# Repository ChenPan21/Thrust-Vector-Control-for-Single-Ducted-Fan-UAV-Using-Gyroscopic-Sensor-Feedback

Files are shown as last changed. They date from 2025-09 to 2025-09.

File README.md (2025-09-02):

<p align="right">
  <a href="README-en.md">English</a> | <a href="README.md">中文</a>
</p>

# 单函道风扇无人机的推力矢量控制(TVC)

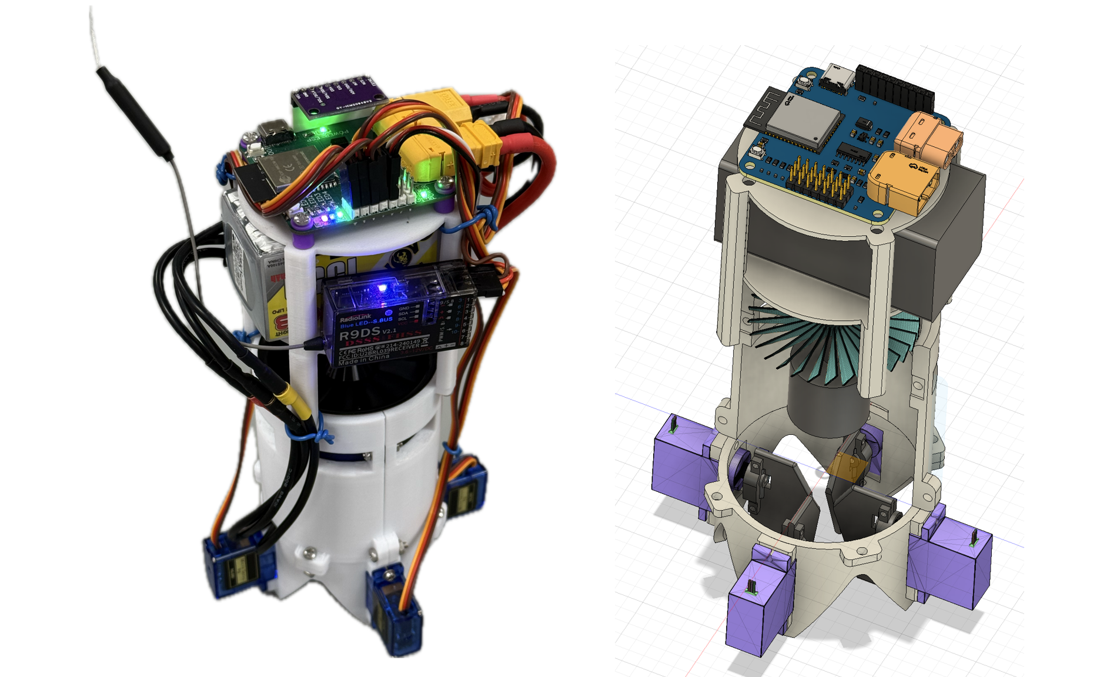
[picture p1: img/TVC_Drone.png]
项目成品图


这是一个关于使用陀螺仪传感器反馈，为单函道风扇无人机（UAV）实现推力矢量控制（Thrust Vector Control, TVC）的项目。

---

## 🚀 项目简介

### 什么是推力矢量控制 (TVC)？

让我们先来玩一个小游戏，想象一下，你想要用手掌托住一瓶倒立的矿泉水，并让它保持垂直不倒。

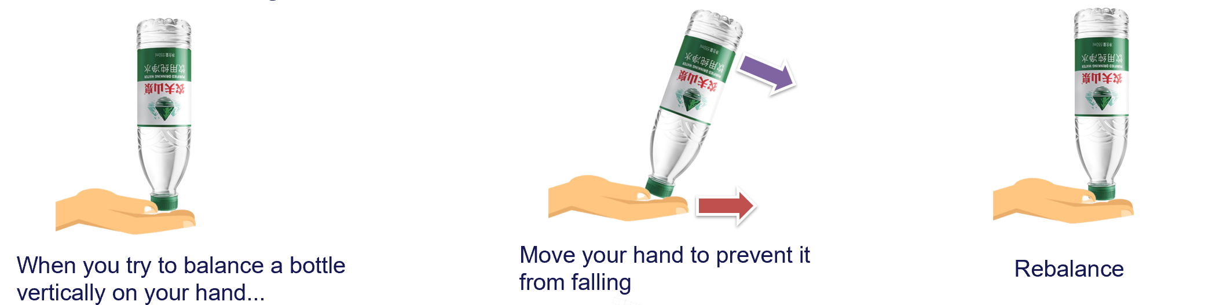
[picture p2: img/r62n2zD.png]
倒立水瓶
 
当水瓶开始向左倾斜时，你的手会下意识地向左移动，产生一个反作用力，将水瓶推回中心。当它向右倾斜时，你的手又会向右移动来纠正它，从而实现平衡。
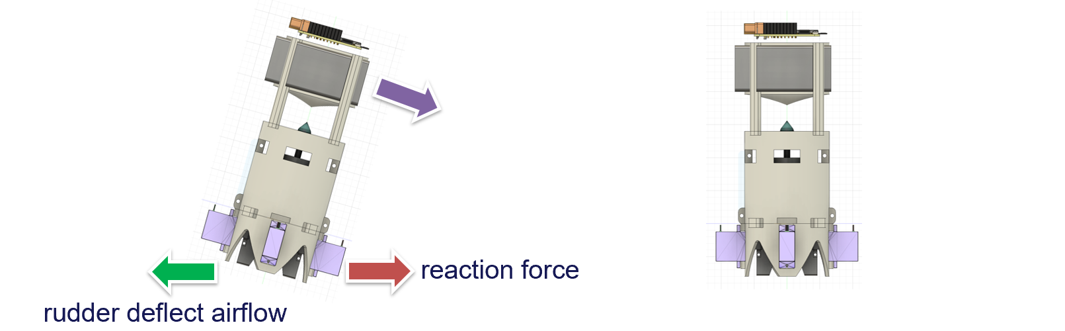
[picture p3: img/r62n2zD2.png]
本项目TVC 原理

本项目无人机的**推力矢量控制**原理与此非常相似。它底部的四个舵面就像你的手，机身就像那瓶水。当无人机的陀螺仪传感器（相当于咱们的眼睛和平衡感）检测到机身发生倾斜时，控制器会立刻命令相应的舵面偏转，改变高速气流的方向。这样，气流就会产生一个反作用力，将机身“推”回平衡状态。

通过对这个反作用力进行精准、快速的控制，无人机就能在没有多个螺旋桨的情况下，实现悬停、滚转、俯仰和偏航等全姿态的稳定飞行。

### 项目意义

与依赖电机转速差进行姿态控制的传统多旋翼无人机相比，单函道风扇 TVC 无人机具有以下显著优势：

* **增强的机动性:** 通过舵面偏转产生额外的控制力矩，显著增强了悬停和低速飞行时的姿态调整能力。
* **解耦控制:** 避免了传统多旋翼“倾斜机身以实现偏航”的耦合问题，可以实现更精准的平移和转向操控。
* **更高的安全性与效率:** 函道设计包裹了高速旋转的桨叶，提升了安全性，同时优化了气动效率。
* **结构简化:** 仅需1个函道风扇+4个舵机即可实现全姿态控制，大幅简化了机械结构和电子驱动部分，减轻了重量和体积。

---

### 项目难点

* **高频姿态解算与实时闭环控制**
* **TVC控制抵消单发动机的自旋扭矩**
* **推力矢量舵机控制与气动响应非线性**
* **硬件轻量化设计 | 高低功率电源隔离 | FreeRTOS 多任务并行**

---

## 🛠️ 硬件设计

硬件系统是实现稳定飞行的基础。本项目经历了从分布式模块到高度集成化设计的多次迭代，最终实现了结构紧凑、高可靠性的硬件平台。

### 1. 机械结构

机械结构经过了三个主要版本的迭代，全部采用 PLA 材料进行 3D 打印，兼顾了轻量化与结构刚性。

* **V1: 初版验证**
    <br>
    <p align="center">
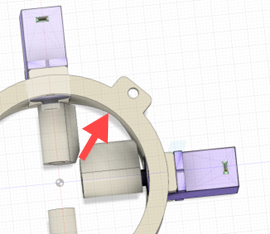
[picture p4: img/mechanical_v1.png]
第一版设计
      
    </p>
    
    * 采用分体式结构，主要用于验证各部件的装配尺寸和干涉问题。
    * **问题:** 封闭的底部结构阻挡了对角线方向的气流，导致矢量控制失效。

* **V2: 气流优化与双电池方案**

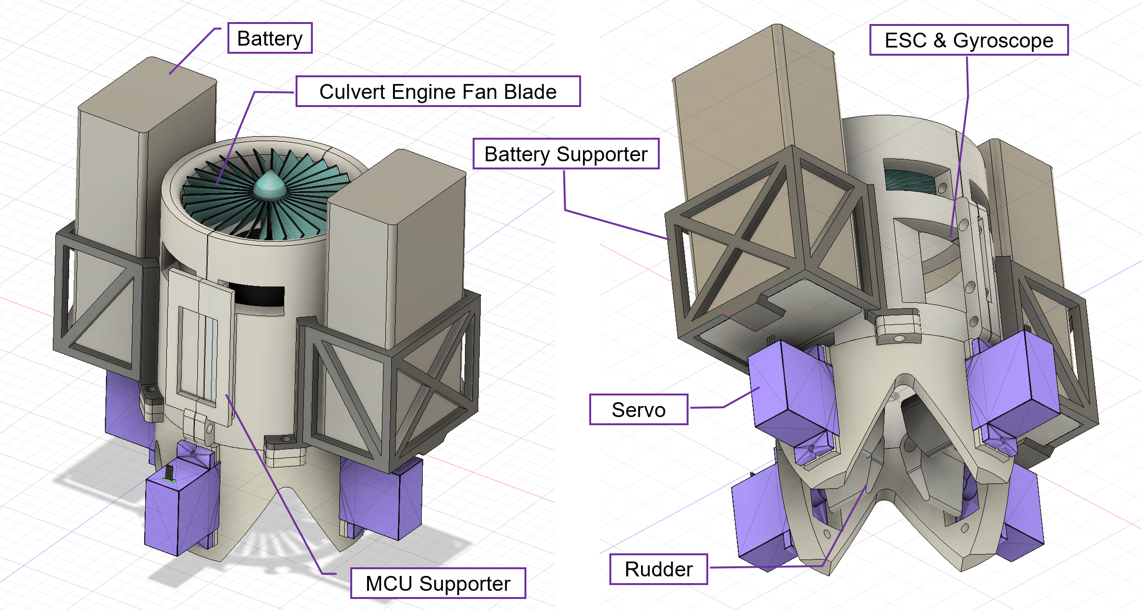
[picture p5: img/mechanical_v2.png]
第二版结构图
  

    * 底部对角区域进行大面积开孔，解决了气流遮挡问题，并增大了舵机行程。
    * 采用双电池对称布局以平衡重心，并设计了电调散热通道。
    * **问题:** 双电池方案导致总重量过大，接近推力极限，续航能力差。

* **V3: 最终版 - 垂直堆叠集成化设计**

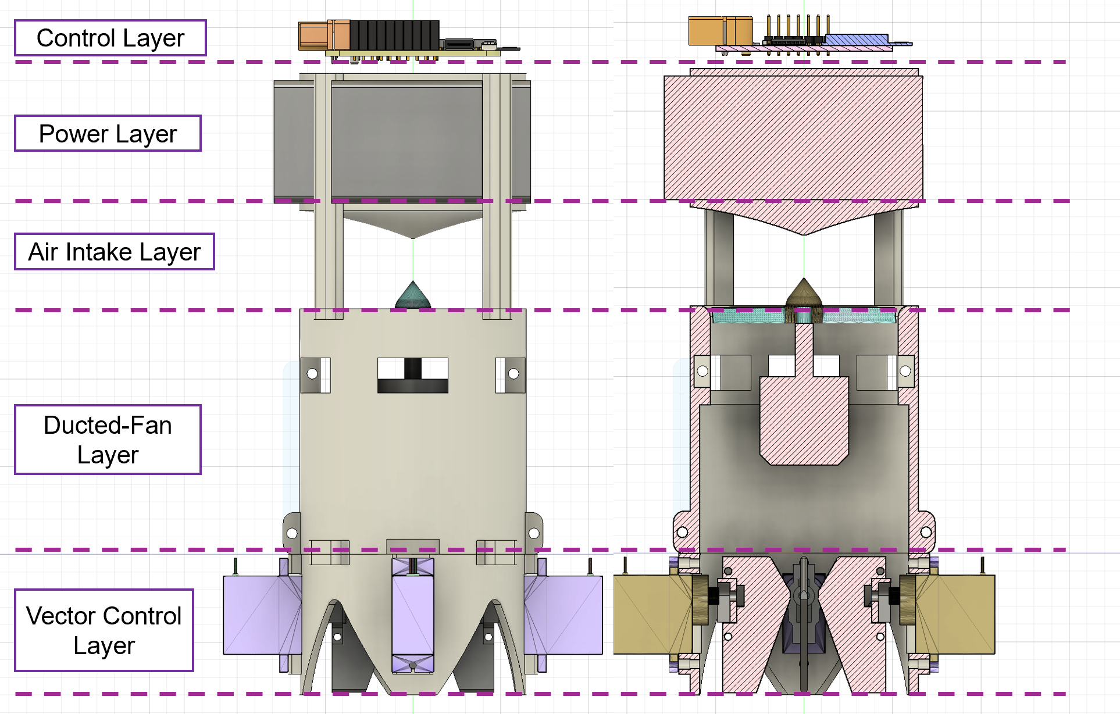
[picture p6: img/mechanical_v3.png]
最终版分层结构图
   
    
    * 采用五层垂直堆叠结构，将重心集中于中轴线，减小了滚转/俯仰转动惯量。
    * 改用单电池方案，显著减轻了整机重量。
    * **优势:** 高度集成化，简化了布线，减少了电磁干扰，提升了控制响应速度。

### 2. 电子系统

电子系统的核心是定制化的 PCB，它集成了主控、电源管理、传感器接口和驱动等于一体。
本项目主控板原理图如下所示：
<br>
<p align="center">
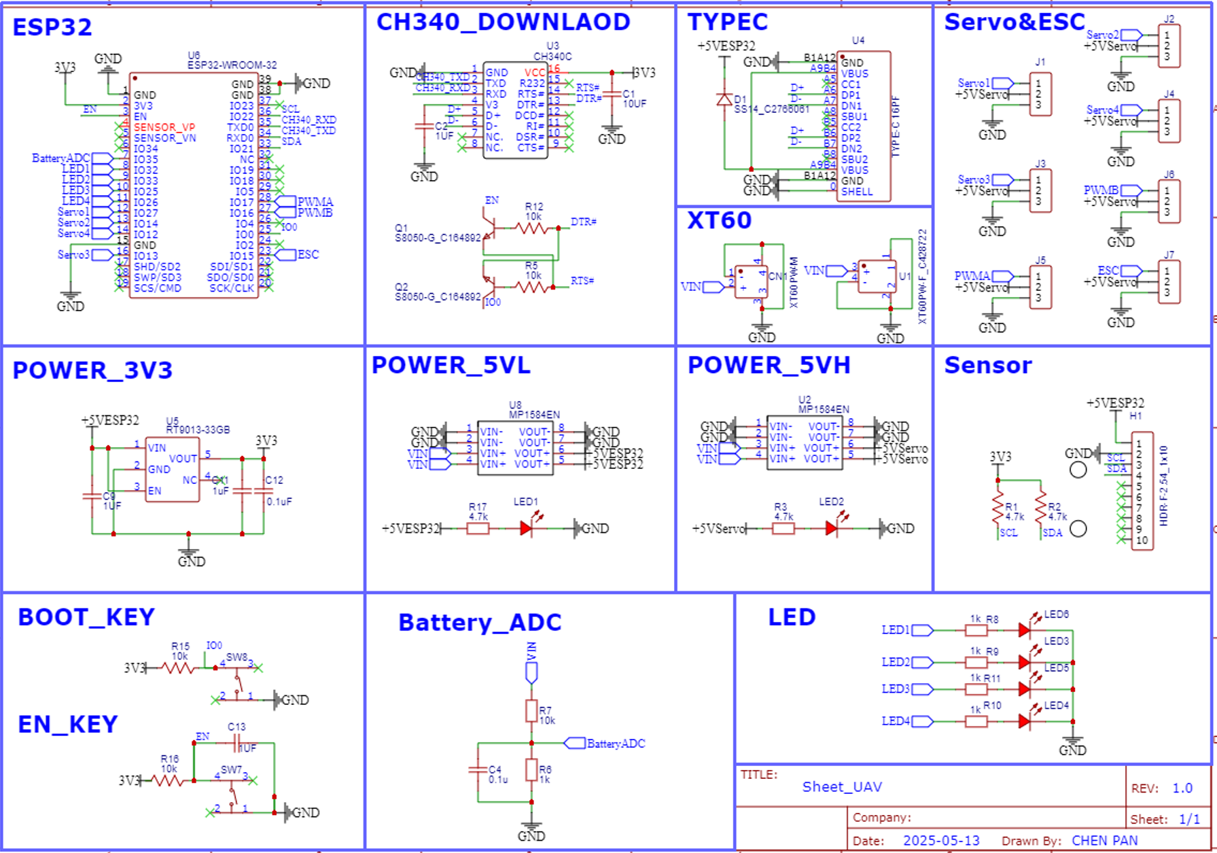
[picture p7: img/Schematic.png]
  
</p>

硬件系统架构：
<br>
<p align="center">
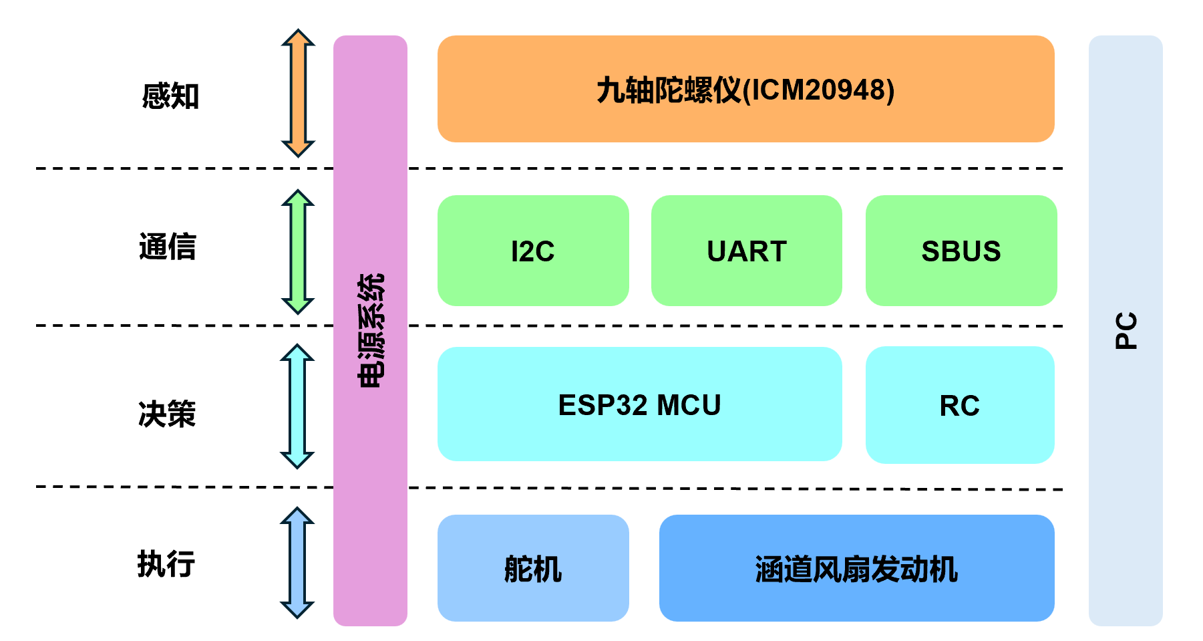
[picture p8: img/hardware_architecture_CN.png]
  
</p>

* **核心控制器:** ESP32-WROOM-32 模块，其双核处理器和 FreeRTOS 支持为实时多任务处理提供了强大的算力保障。
* **传感器:** ICM-20948 九轴陀螺仪，通过其内置的数字运动处理器（DMP）直接输出四元数姿态数据，大大减轻了主控的计算负担。
* **硬件系统架构:** 遵循“感知→决策→执行”的闭环逻辑。

<br>
<p align="center">
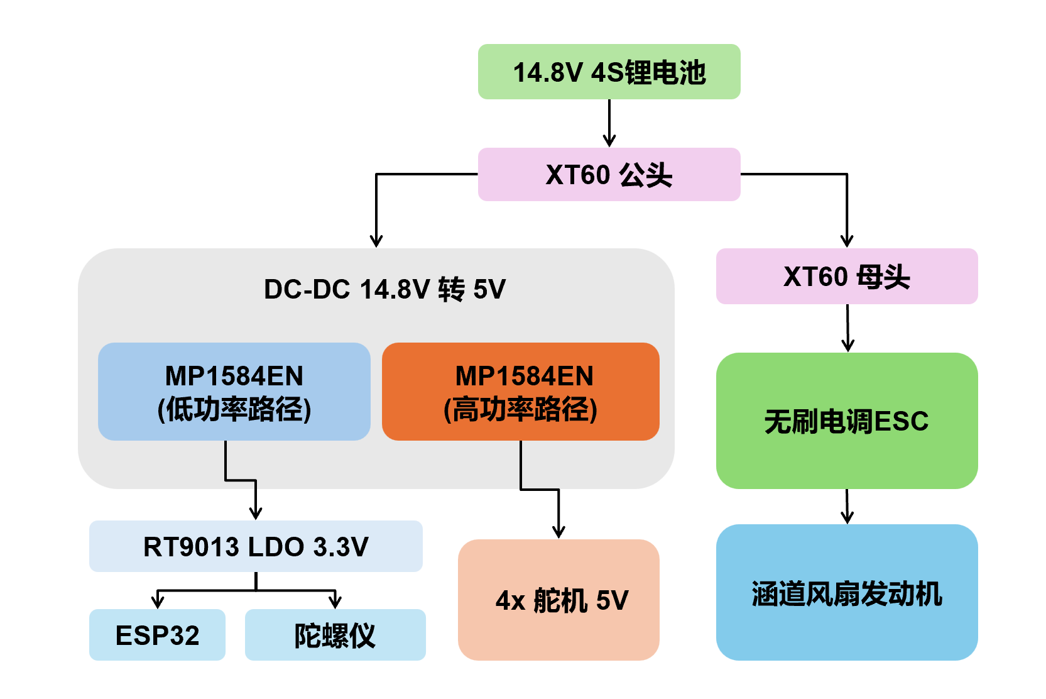
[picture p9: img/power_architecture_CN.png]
电源架构图
  
</p>

* **电源架构:** 采用单电池供电，通过两个独立的 DC-DC 模块实现高/低压分离供电。一路经 LDO 为 ESP32 和陀螺仪提供纯净的 3.3V 电源；另一路直接为4个舵机提供 5V 电源，满足其瞬时大电流需求。

* **四层 PCB布局:**
    <br>
    <p align="center">
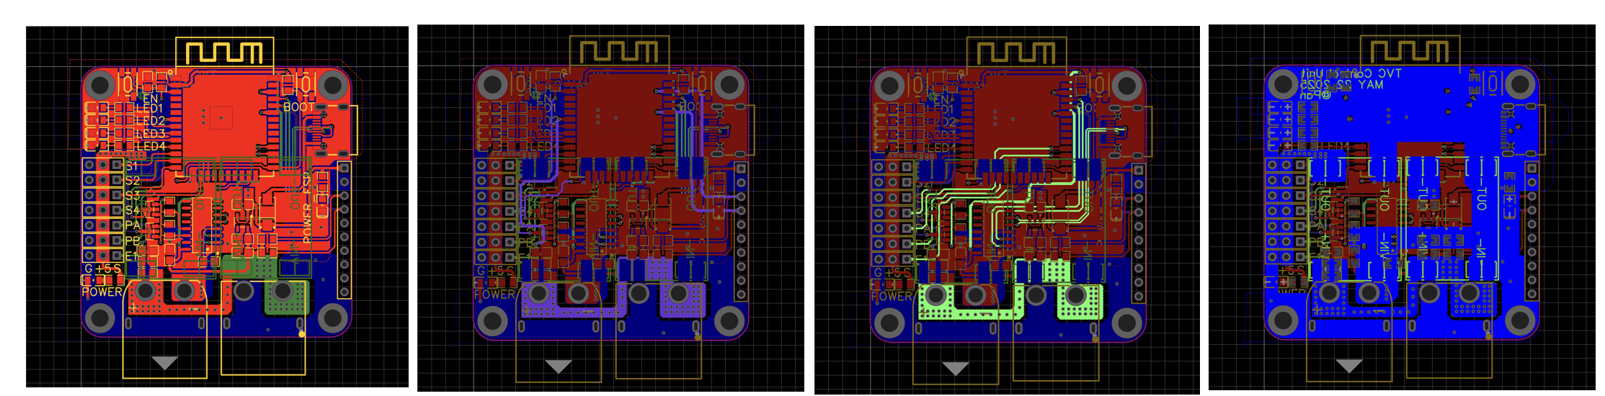
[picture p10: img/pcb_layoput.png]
四层PCB Layout
      
    </p>
    
    * 顶层与底层：放置主要元器件和完整的接地层。
    * 内部信号层：走关键信号线，如 I2C 和 PWM，以减少干扰。
    * 大面积铺铜与过孔设计，以支持大电流传输。
    * 功率地和信号地采用0欧姆电阻连接。
    * 集成了自动下载电路、电源反接保护和状态指示灯等辅助功能。
* **PCB实物图:**
<br>
<p align="center">
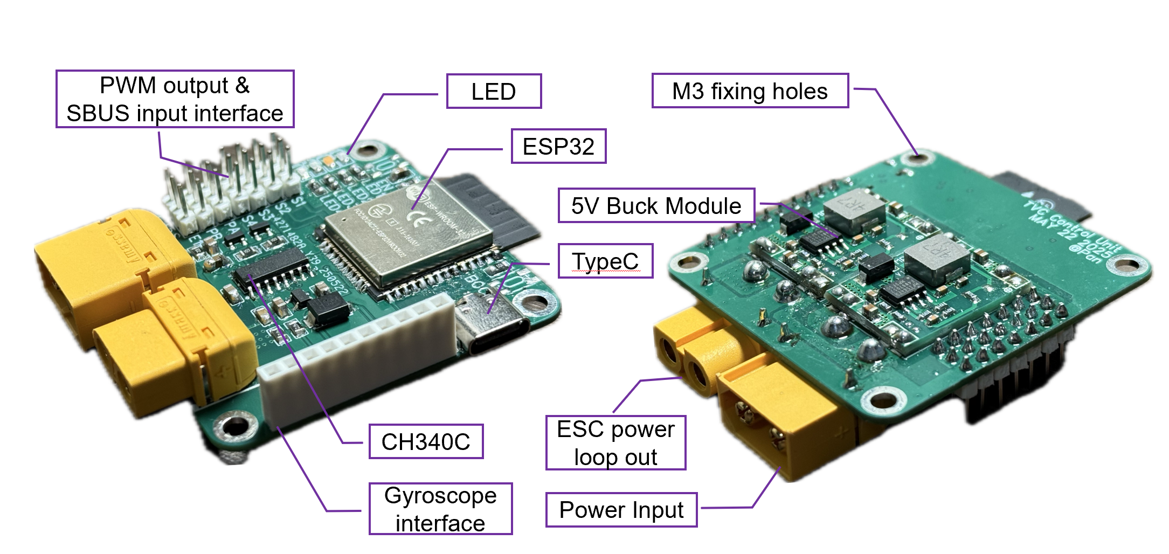
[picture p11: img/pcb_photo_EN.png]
PCB实物正反面图
  
</p>
<br>

---

## 💻 软件与算法

软件系统基于 FreeRTOS 实时操作系统构建，通过多任务并行处理，确保了控制系统的实时性和可靠性。

### 1. 软件架构
<br>
<p align="center">
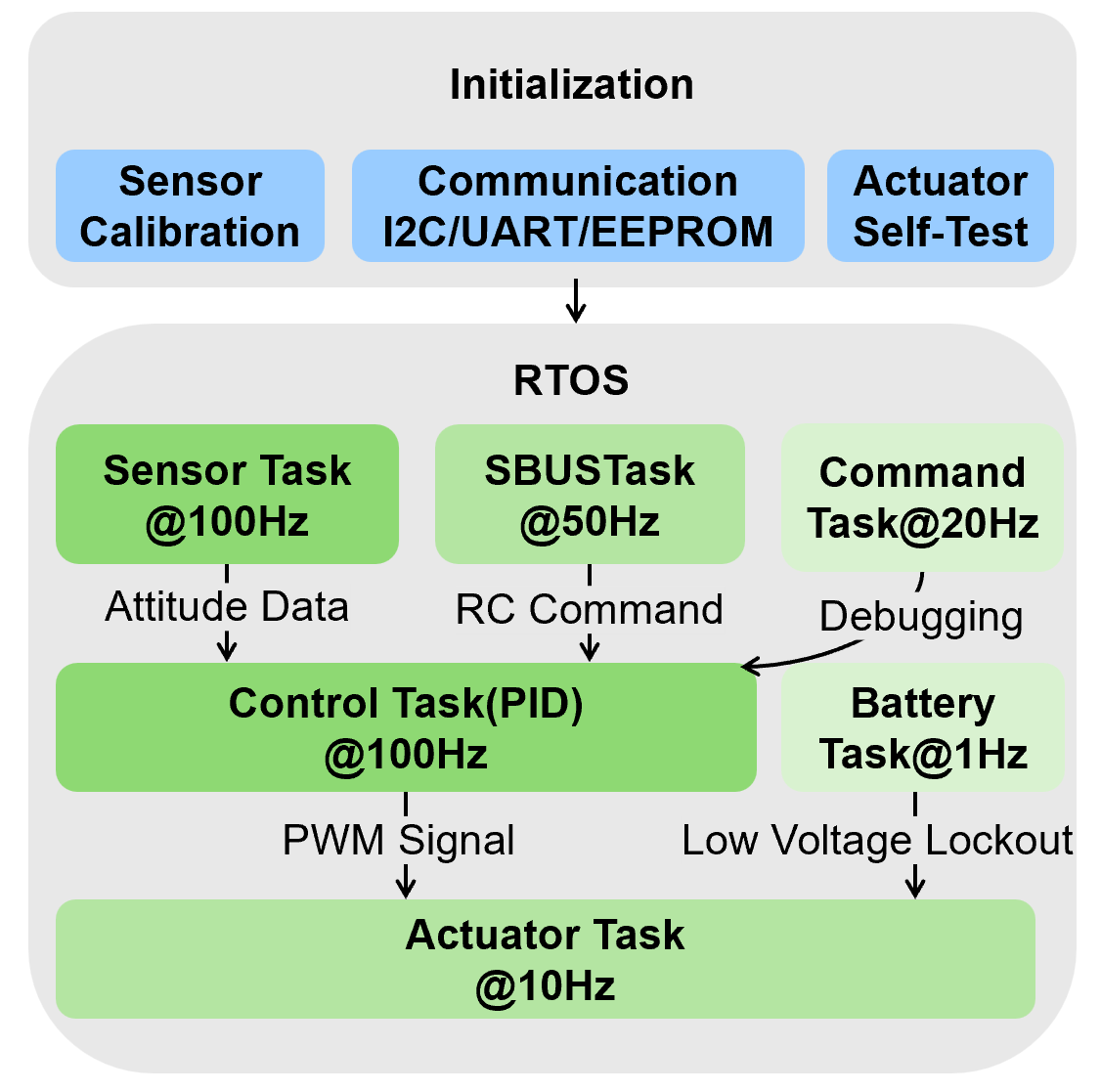
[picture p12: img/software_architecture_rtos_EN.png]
软件系统架构图
  
</p>

系统分为多个具有不同优先级和运行频率的任务：
* **高优先级任务:**
    * `SensorTask` (100Hz): 读取 IMU 数据并解算为欧拉角。
    * `ControlTask` (100Hz): 执行 PID 运算，生成舵机控制信号。
* **中优先级任务:**
    * `SBUSTask` (50Hz): 解析遥控器 SBUS 信号，映射为目标姿态。
* **低优先级任务:**
    * `BatteryTask` (1Hz): 监控电池电压，实现低压保护。
    * `ActuatorTask` (10Hz): 将控制信号输出至舵机。

### 2. PID 闭环控制

控制核心是 PID 算法，它根据当前姿态与目标姿态的误差来动态调整舵机角度。

* **滚转/俯仰:** 采用角度环控制，直接追踪遥控器设定的目标角度。
* **偏航:** 采用角速率环控制，追踪目标角速度，响应更平滑。
<br>
<p align="center">
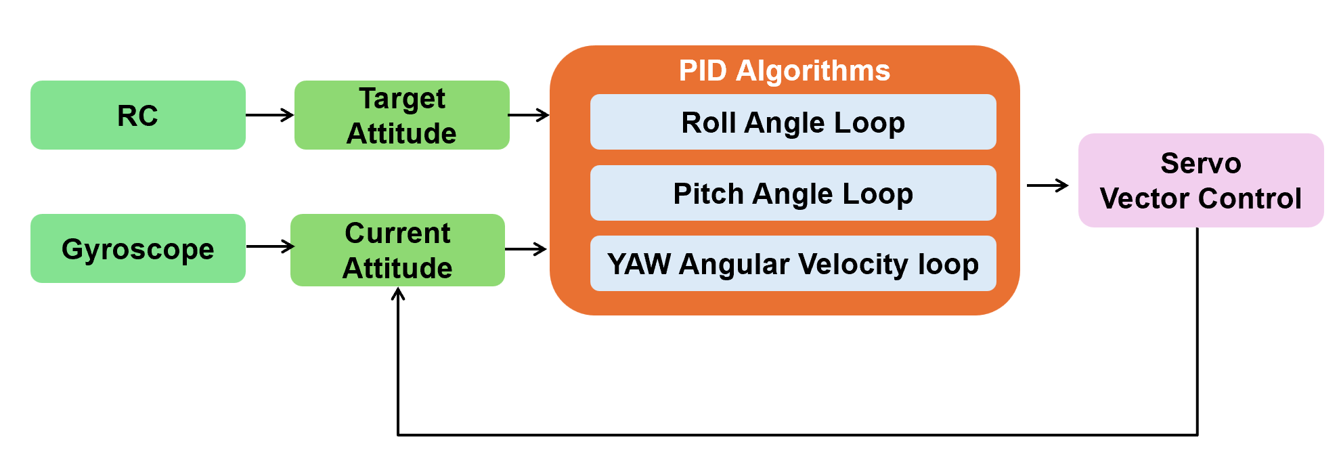
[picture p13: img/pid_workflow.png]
PID闭环控制流程图
  
</p>
<br>

### 3. 推力矢量映射

PID 的输出值通过以下伪代码逻辑映射到四个舵机的具体偏转角度，从而实现对推力的矢量控制。

```cpp
// 矢量控制伪代码
if (!isArmed || lowVoltage) {
    set all servos to 90°; // 安全模式下舵机回中
} else {
    // 根据PID输出值和偏置，计算每个舵机的目标角度
    frontServo = 90 + pitchOut + frontBias + yawOut;
    backServo  = 90 - pitchOut + backBias - yawOut;
    leftServo  = 90 + rollOut  + leftBias  + yawOut;
    rightServo = 90 - rollOut  + rightBias - yawOut;
    
    send PWM to servos; // 发送PWM信号驱动舵机
}
```

---

## 🔬 测试与验证

为验证设计的有效性，我们进行了一系列地面和系留飞行测试。

### 1. 地面推力测试

我们搭建了专用的推力测试平台，以表征函道风扇的性能。

* **结果:** 测得最大推力约为 **700克**，且推力与油门近似呈线性关系。
<br>
<p align="center">
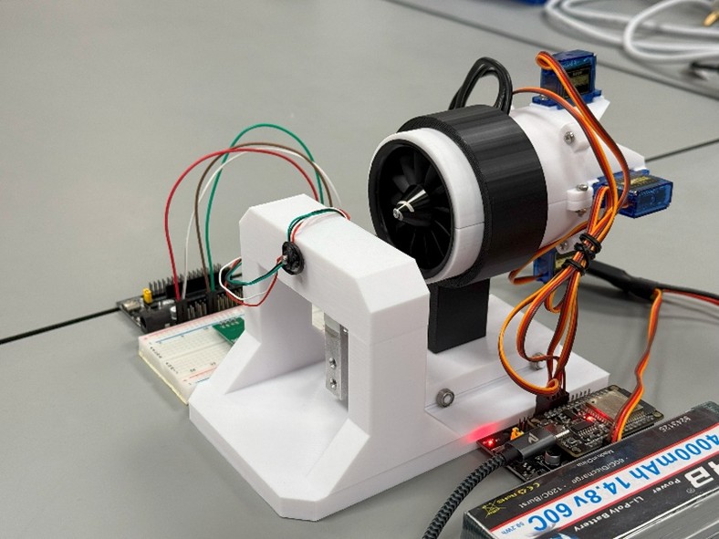
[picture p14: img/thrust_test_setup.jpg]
地面推力测试平台
  
</p>
<p align="center">
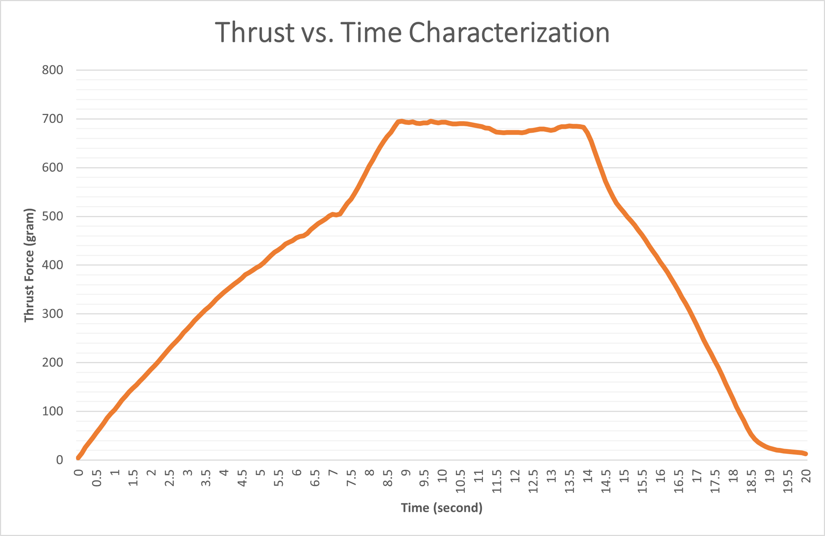
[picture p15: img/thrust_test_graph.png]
推力-时间曲线图
  
</p>
<br>

### 2. 系留飞行测试

通过四根柔性绳索将无人机悬挂，在限制位移的同时，验证矢量控制系统的姿态调节能力。

* **结果:** 无人机能够稳定地响应遥控指令，在多个方向上实现姿态控制，并具备一定的抗干扰能力。测试验证了矢量控制逻辑的可行性。
<br>
<p align="center">
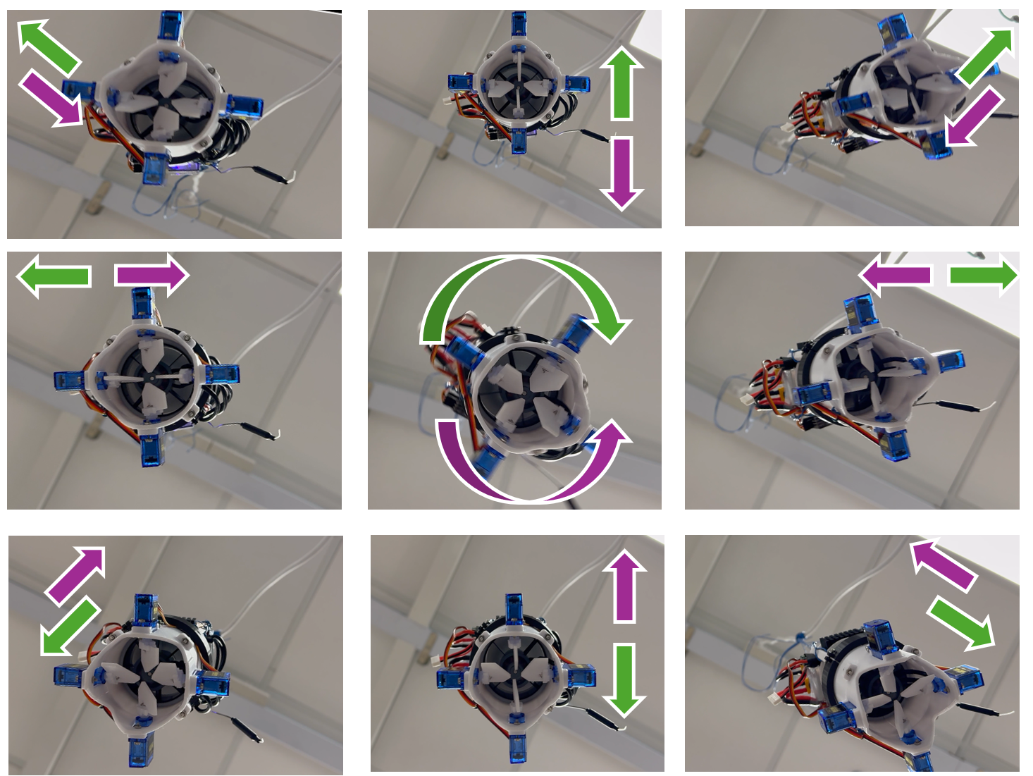
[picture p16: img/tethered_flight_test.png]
系留飞行测试效果图
  
</p>
<br>

---

## 存在的问题与未来工作

* **当前问题:** 在高油门（>70%）时，机身会出现低频抖动。这可能是由于单环 PID 易激发结构共振，以及舵机响应的相位滞后导致了过度补偿。
* **未来解决方案:**
    * **算法改进:** 采用**串级 PID**（外环姿态，内环角速率），并增加陷波滤波器和基于油门的增益调度。
    * **硬件改进:** 尝试使用**共轴反桨**函道风扇，从物理上抵消自旋力矩，从而简化控制回路，降低谐振风险。

---

## 💡 总结与创新

本项目成功开发并验证了一套紧凑的单函道风扇 TVC 无人机系统，其主要创新点包括：

1.  **机械创新:** 采用**垂直堆叠**的集成化设计，集中了重心，降低了转动惯量，同时实现了轻量化。
2.  **电气创新:** 创新的**单电池高低压分离供电方案**和高度集成的**四层 PCB**，显著减重并提升了系统可靠性。
3.  **算法创新:** 在 FreeRTOS 上整合了 IMU-DMP、PID 和 SBUS 解码，实现了**高频率、低延迟**的闭环控制，仅用四个小舵面就完成了传统多旋翼的复杂姿态控制。

该研究证实了 TVC 技术在单函道无人机姿态调节中的可行性，为未来在复杂环境中应用的高机动性、高安全性无人机技术奠定了实践基础。

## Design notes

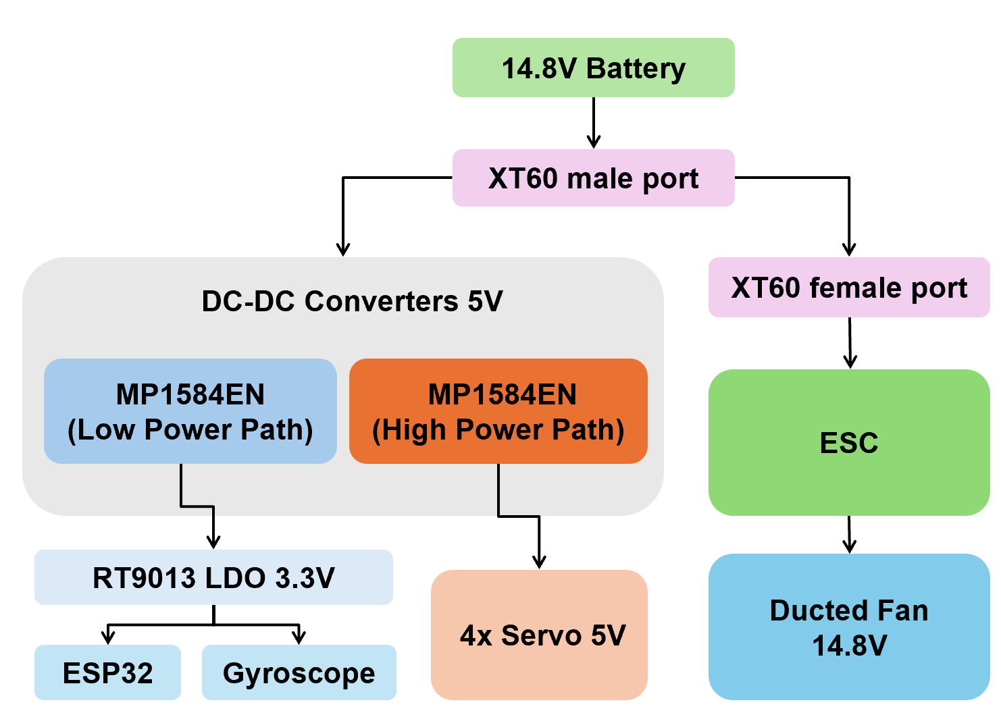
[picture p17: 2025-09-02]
img/power_architecture_EN.png

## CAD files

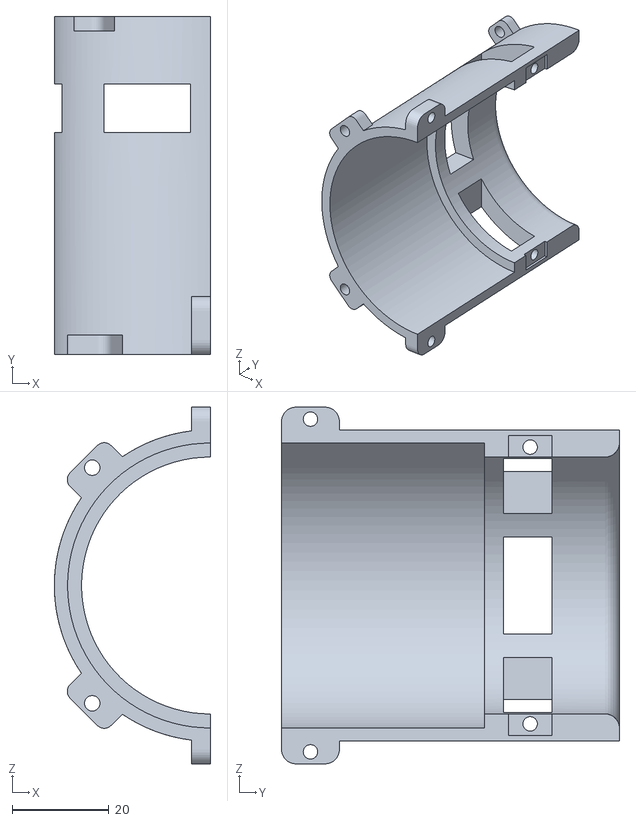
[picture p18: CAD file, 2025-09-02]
3Dmodel/TOPV2.stl
32.4 x 70.0 x 73.9

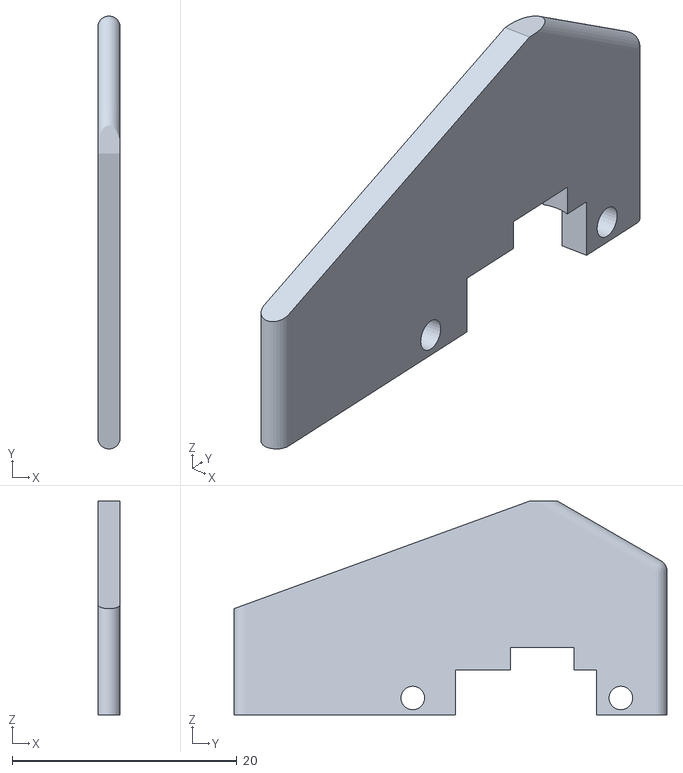
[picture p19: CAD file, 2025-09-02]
3Dmodel/fin.stl
2.00 x 38.5 x 19.0

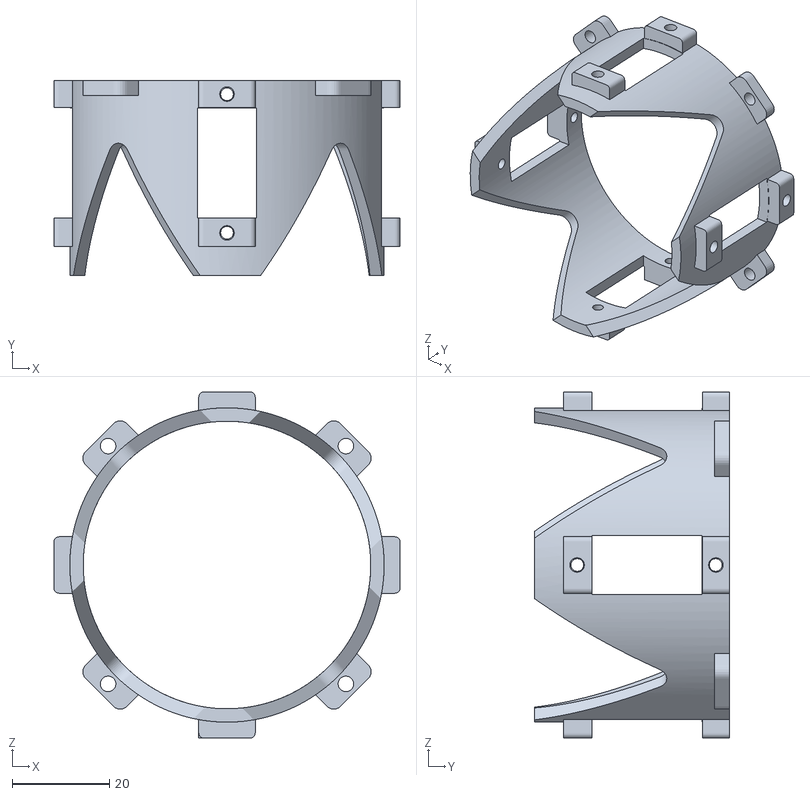
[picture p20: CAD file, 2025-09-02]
3Dmodel/Bottom.stl
71.0 x 40.0 x 71.0

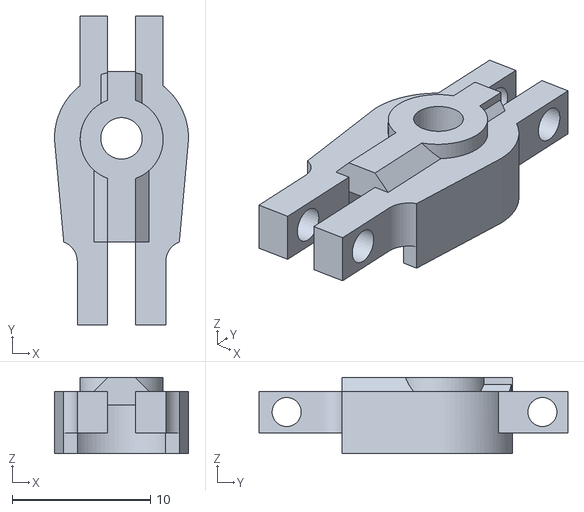
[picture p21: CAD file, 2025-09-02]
3Dmodel/FINCONNCETOR.stl
9.70 x 22.4 x 5.50

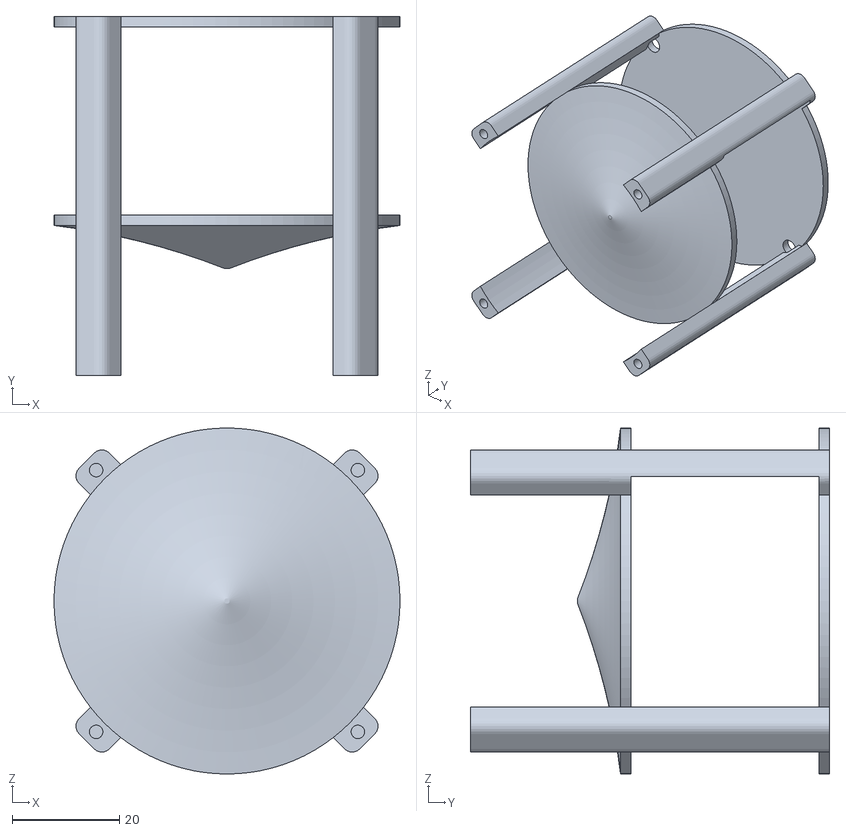
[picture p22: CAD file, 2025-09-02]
3Dmodel/Support.stl
64.5 x 67.0 x 64.5

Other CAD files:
3Dmodel/TOP (1).stl

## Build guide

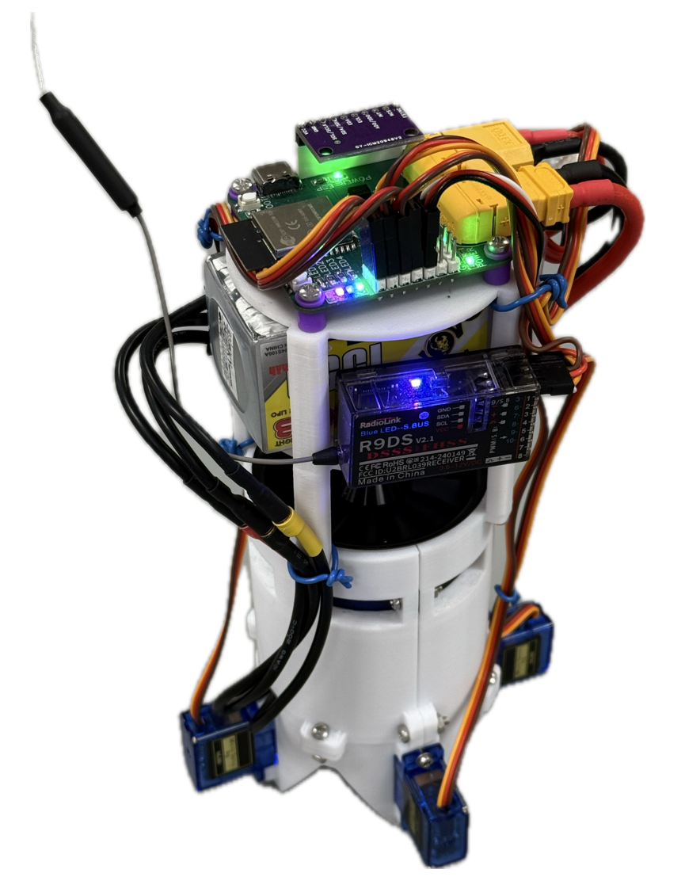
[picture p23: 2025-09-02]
img/drone_final_assembly(2).png

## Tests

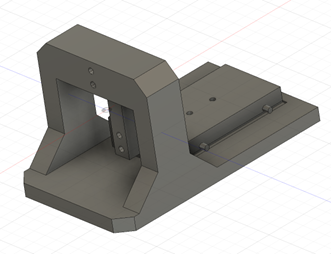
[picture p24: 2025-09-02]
img/thrust_test_setup.png

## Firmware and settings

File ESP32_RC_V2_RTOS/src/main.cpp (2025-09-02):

#include <Wire.h>
#include "ICM_20948.h"
#include <PID_v1.h>
#include <ESP32Servo.h>
#include <EEPROM.h>
#include "sbus.h" 
#include "freertos/FreeRTOS.h"
#include "freertos/task.h"
#include "freertos/semphr.h"

// Function prototypes
float mapStickToAngle(int value, int center, int min_val, int max_val, float max_angle);

// SBUS object and variable declarations
bfs::SbusRx sbus(&Serial2, 17, -1, true);  // GPIO17 for SBUS reception
bfs::SbusData sbusData;

// Remote control channel mapping
#define ROLL_CHANNEL 0     // Roll channel (left/right) - Channel 0
#define PITCH_CHANNEL 1    // Pitch channel (forward/backward) - Channel 1
#define THROTTLE_CHANNEL 2 // Throttle channel - Channel 2
#define YAW_CHANNEL 3      // Yaw channel (self-rotation) - Channel 3
#define ARM_CHANNEL 4      // Arm channel - Channel 4

// Remote control neutral values
#define ROLL_CENTER 1000   // Roll neutral value
#define PITCH_CENTER 852   // Pitch neutral value
#define YAW_CENTER 1002    // Yaw neutral value

// Remote control actual range
#define ROLL_MIN 306      // Roll minimum value
#define ROLL_MAX 1693     // Roll maximum value
#define PITCH_MIN 306     // Pitch minimum value
#define PITCH_MAX 1662    // Pitch maximum value
#define YAW_MIN 306       // Yaw minimum value
#define YAW_MAX 1688      // Yaw maximum value

// Control parameters
#define STICK_DEADZONE 50  // Stick dead zone value
#define ANGLE_MAX 30.0f    // Maximum angle limit
#define CONTROL_SMOOTH_FACTOR 0.05f // Control smoothing factor (smaller values make movement slower)

//******************************************//
//****************Serial Parameter Tuning***************//
// Serial command handling
#define SERIAL_PORT Serial
#define AD0_VAL 0 // AD0 pin is grounded when 0, VCC when 1

// EEPROM configuration
#define EEPROM_SIZE 512
#define PID_ADDR 0  // PID parameter storage start address

struct PIDParams {
  double Kp_roll;
  double Ki_roll;
  double Kd_roll;
  double Kp_pitch;
  double Ki_pitch;
  double Kd_pitch;
  double Kp_yaw;
  double Ki_yaw;
  double Kd_yaw;
};

PIDParams pidParams; // Current PID parameters

ICM_20948_I2C myICM;

// Hardware configuration
#define ESC_PWM_PIN 15
#define PWM_FREQ 50
#define PWM_RESOLUTION 14
#define FULL_DUTY_CYCLE ((1 << PWM_RESOLUTION) - 1)
#define MIN_THROTTLE 1000    // Microseconds
#define MAX_THROTTLE 2000    // Microseconds
#define DISARM_DUTY 0        // Duty cycle when safety locked

// PWM calculation
const float usPerTick = 1000000.0 / PWM_FREQ / FULL_DUTY_CYCLE;
const int minDuty = MIN_THROTTLE / usPerTick;
const int maxDuty = MAX_THROTTLE / usPerTick;
const int pwmChannel = 7;

// Calibration parameters
const float TARGET_ROLL = -177.0;    // Target Roll angle (
const float TARGET_PITCH = -1.0;    // Target Pitch angle
const float ANGLE_TOLERANCE = 5; // Allowed angle error (±2°)
const int STABLE_COUNT_THRESHOLD = 50; // Number of consecutive stable samples
const int CALIBRATION_TIMEOUT = 60000; // Calibration timeout (60 seconds)

// Servo pin definitions (according to your configuration)
const int pinFront = 27;  // Front servo 1 
const int pinRight = 14;  // Right servo 2
const int pinBack  = 13;  // Back servo 3
const int pinLeft  = 12;  // Left servo 4

// Servo offset calibration (according to your configuration)
const int Frontbias = -3;
const int Rightbias = 5;
const int Backbias  = 16;
const int Leftbias  = 4;

// Servo objects
Servo servoFront;
Servo servoRight;
Servo servoBack;
Servo servoLeft;

// System status
bool isArmed = false;  // Default: not armed
bool isPrintingError = true;  // Default: print angle error data
bool isLowVoltage = false;    // Low voltage status flag

// ============== Debug Mode Switches ==============
// Uncomment/comment the following macro definitions to switch debug mode
//#define DEBUG_ROLL
//#define DEBUG_PITCH
//#define DEBUG_YAW
#define FULL_CONTROL

// ============= PID Parameter Configuration ==============
double Kp_roll, Ki_roll, Kd_roll;
double Kp_pitch, Ki_pitch, Kd_pitch;
double Kp_yaw, Ki_yaw, Kd_yaw;

// ============== Control Object Declarations ==============
double rollSetpoint=0, rollInput, rollOutput;
PID rollPID(&rollInput, &rollOutput, &rollSetpoint, Kp_roll, Ki_roll, Kd_roll, DIRECT);

double pitchSetpoint=0, pitchInput, pitchOutput;
PID pitchPID(&pitchInput, &pitchOutput, &pitchSetpoint, Kp_pitch, Ki_pitch, Kd_pitch, DIRECT);

double yawSetpoint=0, yawInput, yawOutput;
PID yawPID(&yawInput, &yawOutput, &yawSetpoint, Kp_yaw, Ki_yaw, Kd_yaw, DIRECT);

// ============== PID Input Parameters ==============
float gyroX, gyroY, gyroZ, yaw_init, targetRoll, targetPitch, targetYaw;
float gyroYawRate = 0; // Z-axis angular velocity (°/s)

// LED pin definitions
#define LED_CALIBRATION 33    // Purple LED - Gyroscope calibration indicator
#define LED_ERROR 32          // Red LED - Error status
#define LED_PID_ACTIVE 25     // Blue LED - PID control active status
#define LED_ARMED 26          // Green LED - System armed status
#define BATTERY_PIN 35        // Battery voltage sampling pin

// Battery voltage related parameters
#define VOLTAGE_DIVIDER_RATIO 11.0  // Voltage divider ratio (10K + 1K) / 1K
#define ADC_REF_VOLTAGE 3.3         // ESP32 ADC reference voltage
#define ADC_RESOLUTION 4095         // ESP32 ADC resolution
#define LOW_VOLTAGE_THRESHOLD 13.5  // Low voltage warning threshold (4S battery)
#define VOLTAGE_CHECK_INTERVAL 1000 // Voltage check interval (milliseconds)
#define VOLTAGE_CALIBRATION 1.122    // Voltage calibration coefficient (adjust based on actual measurements)

// PWM channel definitions
#define PWM_CHANNEL_CALIBRATION 0
#define PWM_CHANNEL_ERROR 1
#define PWM_CHANNEL_PID 2
#define PWM_CHANNEL_ARMED 3

float YAW_RC = 0.0f; // Remote control yaw smoothing variable
#define YAW_RC_MAX 35.0f

// YAW rate mode flag
bool isYawRateMode = false;

// YAW rate target
float yawTargetRate = 0.0f;

// Mutex and task handles
SemaphoreHandle_t dataMutex;
TaskHandle_t sensorTaskHandle = NULL;
TaskHandle_t controlTaskHandle = NULL;
TaskHandle_t actuatorTaskHandle = NULL;
TaskHandle_t sbusTaskHandle = NULL;
TaskHandle_t batteryTaskHandle = NULL;
TaskHandle_t lowPriorityTaskHandle = NULL;

// Function declarations
void Calibration();//Gyroscope calibration
void vectorControl();//Vector control function
void executePID(); //PID calculation
void setupESC();// Modified throttle setting function
void setThrottle(float percentage);//Throttle function
void emergencyStop();//Emergency stop
void calibrateESC();//ESC calibration
void printHelp();//Command
void processCommand(String input);//Serial command handling function
void ServoCalibration();//Servo calibration
void updatePIDControllers();
void initEEPROM();
void loadPIDParams();
void savePIDParams();
void saveDefaultParams();
void checkBatteryVoltage();
float readBatteryVoltage();
void printBatteryStatus(float voltage);

// SBUS related function declarations
void processSbusData();
float mapSbusToAngle(int sbusValue);
void updateTargetAngles();

// Add angle wrapping handling function
float normalizeAngle(float angle) {
    while (angle > 180) angle -= 360;
    while (angle < -180) angle += 360;
    return angle;
}

// Calculate the minimum difference between two angles
float angleDifference(float current, float target) {
    float diff = normalizeAngle(current - target);
    return diff;
}

// Function to map remote control values to angles
float mapStickToAngle(int value, int center, int min_val, int max_val, float max_angle) {
    // Apply dead zone
    if (abs(value - center) < STICK_DEADZONE) {
        return 0.0f;
    }
    
    // Select mapping range based on whether input value is greater or less than center value
    if (value > center) {
        return map(value, center + STICK_DEADZONE, max_val, 0, max_angle);
    } else {
        return map(value, min_val, center - STICK_DEADZONE, -max_angle, 0);
    }
}

// ============= FreeRTOS Task Definitions =============
void SensorTask(void *pvParameters) {
    TickType_t xLastWakeTime = xTaskGetTickCount();
    const TickType_t xFrequency = pdMS_TO_TICKS(10); // 100Hz
    for (;;) {
        icm_20948_DMP_data_t data;
        if (myICM.readDMPdataFromFIFO(&data) == ICM_20948_Stat_Ok) {
            if (data.header & DMP_header_bitmap_Quat6) {
                double q1 = (double)data.Quat6.Data.Q1 / 1073741824.0;
                double q2 = (double)data.Quat6.Data.Q2 / 1073741824.0;
                double q3 = (double)data.Quat6.Data.Q3 / 1073741824.0;
                double q0 = sqrt(1.0 - (q1*q1 + q2*q2 + q3*q3));
                float roll = atan2(2*(q0*q1 + q2*q3), 1 - 2*(q1*q1 + q2*q2)) * 180/M_PI;
                float pitch = asin(2*(q0*q2 - q3*q1)) * 180/M_PI;
                float yaw = atan2(2*(q0*q3 + q1*q2), 1 - 2*(q2*q2 + q3*q3)) * 180/M_PI;
                if (!isnan(roll) && !isnan(pitch) && !isnan(yaw)) {
                    xSemaphoreTake(dataMutex, portMAX_DELAY);
                    gyroX = roll;
                    gyroY = pitch;
                    gyroZ = yaw;
                    xSemaphoreGive(dataMutex);
                }
            }
            if (data.header & DMP_header_bitmap_Gyro) {
                float rate = (float)data.Raw_Gyro.Data.Z / 32768.0f * 2000.0f;
                xSemaphoreTake(dataMutex, portMAX_DELAY);
                gyroYawRate = rate;
                xSemaphoreGive(dataMutex);
            }
        }
        vTaskDelayUntil(&xLastWakeTime, xFrequency);
    }
}

void ControlTask(void *pvParameters) {
    TickType_t xLastWakeTime = xTaskGetTickCount();
    const TickType_t xFrequency = pdMS_TO_TICKS(10); // 100Hz
    for (;;) {
        float localGyroX, localGyroY, localGyroZ, localGyroYawRate;
        float localTargetRoll, localTargetPitch, localTargetYaw, localYawTargetRate;
        xSemaphoreTake(dataMutex, portMAX_DELAY);
        localGyroX = gyroX;
        localGyroY = gyroY;
        localGyroZ = gyroZ;
        localGyroYawRate = gyroYawRate;
        localTargetRoll = targetRoll;
        localTargetPitch = targetPitch;
        localTargetYaw = targetYaw;
        localYawTargetRate = yawTargetRate;
        xSemaphoreGive(dataMutex);
        float rollError = angleDifference(localGyroX, localTargetRoll);
        float pitchError = angleDifference(localGyroY, localTargetPitch);
        rollInput = rollError;
        rollSetpoint = 0;
        rollPID.Compute();
        pitchInput = pitchError;
        pitchSetpoint = 0;
        pitchPID.Compute();
        yawInput = localGyroYawRate - localYawTargetRate;
        yawSetpoint = 0;
        yawPID.Compute();
        vTaskDelayUntil(&xLastWakeTime, xFrequency);
    }
}

void ActuatorTask(void *pvParameters) {
    TickType_t xLastWakeTime = xTaskGetTickCount();
    const TickType_t xFrequency = pdMS_TO_TICKS(100); // 10Hz
    for (;;) {
        vectorControl();
        vTaskDelayUntil(&xLastWakeTime, xFrequency);
    }
}

void SBUSTask(void *pvParameters) {
    TickType_t xLastWakeTime = xTaskGetTickCount();
    const TickType_t xFrequency = pdMS_TO_TICKS(20); // 50Hz
    for (;;) {
        processSbusData();
        vTaskDelayUntil(&xLastWakeTime, xFrequency);
    }
}

void BatteryTask(void *pvParameters) {
    TickType_t xLastWakeTime = xTaskGetTickCount();
    const TickType_t xFrequency = pdMS_TO_TICKS(1000); // 1Hz
    for (;;) {
        checkBatteryVoltage();
        vTaskDelayUntil(&xLastWakeTime, xFrequency);
    }
}

void LowPriorityTask(void *pvParameters) {
    TickType_t xLastWakeTime = xTaskGetTickCount();
    const TickType_t xFrequency = pdMS_TO_TICKS(50); // 20Hz
    for (;;) {
        // Serial command handling
        if (Serial.available() > 0) {
            String command = Serial.readStringUntil('\n');
            command.trim();
            processCommand(command);
        }
        // Other auxiliary functions can be added here
        vTaskDelayUntil(&xLastWakeTime, xFrequency);
    }
}
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
void loop() {
    // Empty, all functions are handled by FreeRTOS tasks
}

void Calibration()
{
    SERIAL_PORT.println("Starting calibration...");
    SERIAL_PORT.println("Place the sensor in the target attitude [ Roll=90°, Pitch=1° ]");
  
    // Calibration phase: wait for data to stabilize
    bool isStable = false;
    unsigned long startTime = millis();
    int stableCount = 0;
    unsigned long previousMillis = 0;
    const long blinkInterval = 500; // Blink interval 500ms
    bool ledState = false;
  
    while (!isStable && (millis() - startTime < CALIBRATION_TIMEOUT)) {
      // LED blinking effect
      unsigned long currentMillis = millis();
      if (currentMillis - previousMillis >= blinkInterval) {
        previousMillis = currentMillis;
        ledState = !ledState;
        digitalWrite(LED_CALIBRATION, ledState); // Use digitalWrite instead of PWM
      }

      icm_20948_DMP_data_t data;
      if (myICM.readDMPdataFromFIFO(&data) == ICM_20948_Stat_Ok) {
        if (data.header & DMP_header_bitmap_Quat6) {
          double q1 = (double)data.Quat6.Data.Q1 / 1073741824.0;
          double q2 = (double)data.Quat6.Data.Q2 / 1073741824.0;
          double q3 = (double)data.Quat6.Data.Q3 / 1073741824.0;
          double q0 = sqrt(1.0 - (q1*q1 + q2*q2 + q3*q3));
  
          float roll = atan2(2*(q0*q1 + q2*q3), 1 - 2*(q1*q1 + q2*q2)) * 180/M_PI;
          float pitch = asin(2*(q0*q2 - q3*q1)) * 180/M_PI;
          float yaw = atan2(2*(q0*q3 + q1*q2), 1 - 2*(q2*q2 + q3*q3)) * 180/M_PI;  //YAW

          yaw_init = yaw;
          // Check if within target range
          bool isRollStable = (abs(roll - TARGET_ROLL) < ANGLE_TOLERANCE);
          bool isPitchStable = (abs(pitch - TARGET_PITCH) < ANGLE_TOLERANCE);
  
          if (isRollStable && isPitchStable) {
            stableCount++;
          } else {
            stableCount = 0; // Data fluctuation, reset counter
          }
  
          // Number of consecutive stable samples reaches threshold
          if (stableCount >= STABLE_COUNT_THRESHOLD) {
            isStable = true;
            SERIAL_PORT.println("Calibration complete! System remains locked");
            digitalWrite(LED_CALIBRATION, HIGH); // LED remains on after calibration
          }
        }
      }
    }
  
    if (!isStable) {
      SERIAL_PORT.println("Calibration Overtime! Please check the sensor placement !");
      digitalWrite(LED_CALIBRATION, LOW); // Turn off LED
      digitalWrite(LED_ERROR, HIGH);     // Error LED turns on
      while(1); // Stop running
    }
}

void vectorControl() {
  // If in low voltage state, stop vector control
  if (isLowVoltage) {
    // Return all servos to neutral position
    const int baseAngle = 90;
    servoFront.write(baseAngle + Frontbias);
    servoRight.write(baseAngle + Rightbias);
    servoBack.write(baseAngle + Backbias);
    servoLeft.write(baseAngle + Leftbias);
    return;
  }

  const int baseAngle = 90; // Neutral angle changed back to 90 degrees
  float rollAdj = 0, pitchAdj = 0, yawAdj = 0;

  // Get adjustment amounts for each axis
  #ifdef DEBUG_ROLL
  rollAdj = constrain(rollOutput, -45, 45);
  #elif defined(DEBUG_PITCH)
  pitchAdj = constrain(pitchOutput, -30, 30);
  #elif defined(DEBUG_YAW)
  yawAdj = constrain(yawOutput, -15, 15);
  #else
  rollAdj = constrain(rollOutput, -40, 40);
  pitchAdj = constrain(pitchOutput, -40, 40);
  yawAdj = constrain(yawOutput, -35, 35);
  //yawAdj += (rollOutput + pitchOutput) * 0.3;
  #endif

  // Apply servo offsets and write angles
  //servoFront.write(baseAngle + pitchAdj - yawAdj + Frontbias);
  //servoRight.write(baseAngle - rollAdj - yawAdj + Rightbias);
  //servoBack.write(baseAngle - pitchAdj + yawAdj + Backbias);
  //servoLeft.write(baseAngle + rollAdj + yawAdj + Leftbias);

  //roll
  //servoRight.write(baseAngle + rollAdj + yawAdj + Leftbias);
  //servoLeft.write(baseAngle - rollAdj - yawAdj + Rightbias);
  
  //roll 2 4 
  servoRight.write(constrain(baseAngle + rollAdj + Rightbias- yawAdj ,61+Rightbias,120+Rightbias));
  servoLeft.write(constrain(baseAngle - rollAdj + Leftbias-yawAdj , 61+Leftbias, 120+ Leftbias));
  // servoRight.write(baseAngle + rollAdj + Leftbias);
  // servoLeft.write(baseAngle - rollAdj  + Rightbias);

  
  //pitch 1 3
  servoFront.write(constrain(baseAngle - pitchAdj + Frontbias- yawAdj ,61 + Frontbias,120 + Frontbias));
  servoBack.write(constrain(baseAngle + pitchAdj + Backbias- yawAdj, 61 + Backbias,120+ Backbias));
  // SERIAL_PORT.print(", Pitch:");

}

// ============== Core Control Functions ==============
void executePID() {
  // Check if input values are valid
  if (isnan(gyroX) || isnan(gyroY) || isnan(gyroZ)) {
    SERIAL_PORT.println("Invalid PID input values");
    return;
  }

  // Calculate error (considering angle wrapping)
  float rollError = angleDifference(gyroX, targetRoll);
  float pitchError = angleDifference(gyroY, targetPitch);

  // Roll axis PID (X-axis)
  #if defined(DEBUG_ROLL) || defined(FULL_CONTROL)
  rollInput = rollError;  // Use angle error directly as PID input
  rollSetpoint = 0;      // Target error is 0
  rollPID.Compute();     // Execute PID calculation
  #endif
  
  // Pitch axis PID (Y-axis)
  #if defined(DEBUG_PITCH) || defined(FULL_CONTROL)
  pitchInput = pitchError;  // Use angle error directly as PID input
  pitchSetpoint = 0;       // Target error is 0
  pitchPID.Compute();      // Execute PID calculation
  #endif
  
  // YAW axis rate error closed-loop
  yawInput = gyroYawRate - yawTargetRate; // Input is current angular velocity minus target rate
  yawSetpoint = 0; // Target is 0
  yawPID.Compute();

  // Serial output for rate closed-loop information
  Serial.print("[YAW RATE LOOP] gyroYawRate: ");
  Serial.print(gyroYawRate);
  Serial.print(", targetRate: ");
  Serial.print(yawTargetRate);
  Serial.print(", input(error): ");
  Serial.print(yawInput);
  Serial.print(", output: ");
  Serial.println(yawOutput);

  // Check if PID outputs are valid
  if (isnan(rollOutput) || isnan(pitchOutput) || isnan(yawOutput)) {
    SERIAL_PORT.println("Invalid PID outputs");
    rollOutput = 0;
    pitchOutput = 0;
    yawOutput = 0;
    return;
  }

  // LED indication when PID is active
  if (abs(rollOutput) > 0.1 || abs(pitchOutput) > 0.1 || abs(yawOutput) > 0.1) {
    digitalWrite(LED_PID_ACTIVE, HIGH); // Blue LED turns on
  } else {
    digitalWrite(LED_PID_ACTIVE, LOW);   // Blue LED turns off
  }
}



void setupESC() {
  ledcSetup(pwmChannel, PWM_FREQ, PWM_RESOLUTION);
  ledcAttachPin(ESC_PWM_PIN, pwmChannel);
  
  // Initial safe state: zero signal
  ledcWrite(pwmChannel, DISARM_DUTY);
  Serial.println("System in SAFE MODE (DISARMED)");
}

// Modified throttle setting function
void setThrottle(float percentage) {
  if(!isArmed) {
    Serial.println("Operation denied: Please send ARM command to unlock system first");
    return;
  }
  
  percentage = constrain(percentage, 0.0, 100.0);
  // Calculate with floating point to ensure precision
  int duty = minDuty + (maxDuty - minDuty) * (percentage / 100.0);
  ledcWrite(pwmChannel, duty);
  Serial.print("Throttle set to: ");
  Serial.print(percentage);
  Serial.println("%");
}



void emergencyStop() {
  ledcWrite(pwmChannel, DISARM_DUTY);
  isArmed = false;
  digitalWrite(LED_ARMED, LOW);    // Turn off green LED
  digitalWrite(LED_ERROR, HIGH);  // Red LED turns on
  Serial.println("Emergency stop activated! System locked");
}

void calibrateESC() {
  if(isArmed) {
    Serial.println("System must be locked before calibration!");
    digitalWrite(LED_ERROR, HIGH); // Red LED turns on
    return;
  }
  
  Serial.println("Starting calibration...");
  digitalWrite(LED_CALIBRATION, HIGH); // Purple LED turns on
  
  // Enter calibration mode
  ledcWrite(pwmChannel, maxDuty);
  delay(100);
  ledcWrite(pwmChannel, minDuty);
  delay(4000);
  
  digitalWrite(LED_CALIBRATION, LOW); // Turn off purple LED
  Serial.println("Calibration complete! System remains locked");
}
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
